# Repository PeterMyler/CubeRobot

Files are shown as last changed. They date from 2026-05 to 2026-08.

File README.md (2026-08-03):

 # Robot Rubik's Cube Solver
 
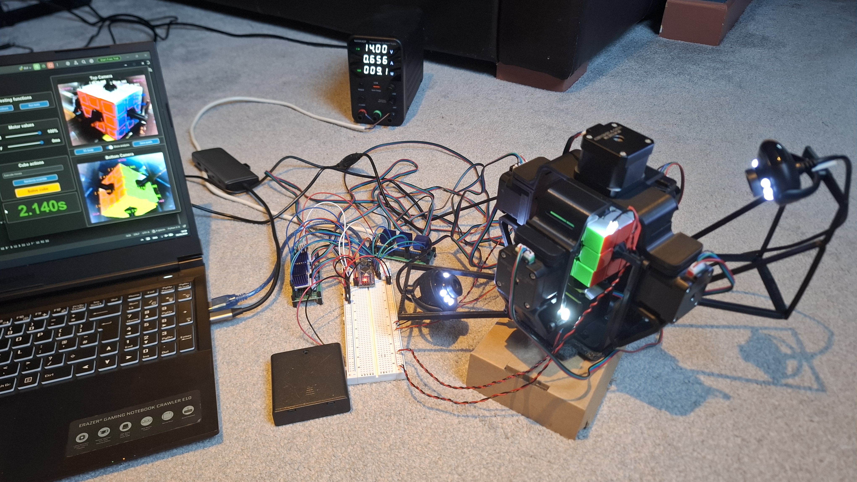
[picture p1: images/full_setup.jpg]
Completed robot assembly


An autonomous robot that scans, solves, and physically executes a solution to a scrambled 3×3×3 Rubik's Cube, with an average solve time of **2.13 seconds**, faster than the current human world record (2.76s).

Final Year Project for BEng (Hons) Electrical and Electronic Engineering (TU821), Technological University Dublin

**Author:** Peter Myler · **Supervisor:** Frank Duignan · May 2026

The project achieved a score of 86% and the student graduated with a 1st Class Honours (3.6 GPA).

**[Watch the demo video](https://youtu.be/nHWHOQfeOHc)**

---

## Overview

Place a scrambled cube in the robot, press one button, and it's solved, meaning no other input required. The system combines:

- A custom 3D-printed frame with **six NEMA 17 stepper motors**, one per cube face
- **Two USB webcams** for full cube-state capture via HSV colour detection
- **Kociemba's two-phase algorithm** to compute a near-optimal solution
- An **Arduino Nano** driving six TMC2208 stepper drivers to execute the moves
- A **Python GUI** for monitoring, calibration, and automated testing

| Metric | Result |
|---|---|
| Mean solve time | 2.13 s |
| Fastest solve | 1.5 s |
| Mean move count | ~19.8 moves (God's Number = 20) |
| Mean turn rate | 15.35 turns/sec |
| Success rate (200 test cycles) | 100% |
| Estimated real-world reliability | ~99% |

---

## Table of Contents

- [How It Works](#how-it-works)
- [Hardware](#hardware)
- [Repository Structure](#repository-structure)
- [Getting Started](#getting-started)
- [Usage](#usage)
- [Testing](#testing)
- [Results](#results)
- [Limitations](#limitations)
- [Future Work](#future-work)

---

## How It Works

```
    Host PC (Python)                 Arduino Nano                  Mechanical Frame
┌──────────────────────┐  USB    ┌─────────────────┐   Step/Dir  ┌──────────────────┐
│ GUI / control        │ serial  │ Firmware:       │   signals   │ 6× TMC2208       │
│ Camera capture (x2)  │ ◄─────► │  parses moves,  │ ──────────► │ drivers → 6×     │
│ HSV colour detection │         │  drives motors  │             │ NEMA 17 motors   │
│ Kociemba solver      │         │  via TMC2208s   │             │ (one per face)   │
└──────────────────────┘         └─────────────────┘             └──────────────────┘
```

1. **Scan** — Two webcams positioned at opposite corners of the frame capture all six faces. Facelet regions are sampled as HSV medians and classified by hue (with saturation/value tie-breaking for red/orange and yellow/green).
2. **Reconstruct** — The motor couplers physically obscure the six centre facelets and some corner facelets. Centres are inferred from the cube's fixed orientation (white up, green front); hidden corner facelets are recovered by matching the two visible facelets of a corner against the eight known corner-piece colour combinations.
3. **Solve** — The reconstructed cube state is passed to [Kociemba's two-phase algorithm](https://github.com/hkociemba/RubiksCube-TwophaseSolver) with a 0.1s search budget, returning a near-optimal move sequence (~20 moves).
4. **Execute** — The move sequence is sent over serial to the Arduino Nano, which generates step/direction pulses for the six TMC2208 drivers at a constant 320 µs step delay.
5. **Verify** — If the detected cubestring is invalid (a misclassified facelet), a single-error correction routine attempts to repair it before falling back to a fresh scan.

For more detail on the colour-space design, hidden-facelet recovery, and the two-phase algorithm, see the full [project report](./FYP_Report.pdf).

---

## Hardware

| Component | Details |
|---|---|
| Motors | 6× NEMA 17 (17HS4401), 1.8° step, 40 N·cm holding torque |
| Motor drivers | 6× TMC2208 silent stepper drivers (StealthChop) |
| Microcontroller | Arduino Nano |
| Cameras | 2× Trust Spotlight Pro USB webcams (640×480) |
| Motor power | 14V bench supply, 4.8A current limit |
| Logic/LED power | 6V (4× AA battery pack) |
| Frame | ~20 custom 3D-printed PLA parts (Fusion 360, printed on a Creality Ender-3 Neo) |
| Cube | Standard 3×3×3 speed cube with centre caps removed for motor couplers |

Full bill of materials is in the [report, Appendix C](./FYP_Report.pdf).

---

## Repository Structure

```
├── rubiks_solver_arduino/ # Arduino Nano firmware (step/direction motor control)
├── python/
│   ├── GUI.py              # Main application — UI, camera feeds, solve control
│   ├── Camera.py           # Camera capture + HSV colour classification
│   ├── Cube.py             # Cubestring construction, solver integration, serial comms
│   └── cube_data.json      # Camera IDs, motor speed/delay, facelet quadrilateral coords
├── cad/                   # Fusion 360 models
├── Test_data/             # Automated test run results (CSV)
├── images/                # Images of the components and frame
└── FYP_Report.pdf         # Full project report
```

---

## Getting Started

### Prerequisites
- Python 3.x
- Arduino IDE (to flash the Nano firmware)
- The hardware described above, assembled per the [CAD files](./cad) and wiring in the report (Section 5.2)

### Python dependencies
```bash
pip install opencv-python customtkinter pyserial RubiksCube-TwophaseSolver magiccube
```
(`cubescrambler` is used for generating WCA-compliant scrambles during testing — see its [repo](https://github.com/koma52/cubescrambler) for installation.)

> **Note:** `RubiksCube-TwophaseSolver` builds large lookup tables (~80 MB) on first use, which can take a while to generate.

### Flashing the firmware
Open `arduino/` in the Arduino IDE and upload to a connected Arduino Nano. No external libraries are required.

### Running the host software
```bash
cd python
python GUI.py
```
Set the correct camera device IDs and Arduino serial port in `cube_data.json` / at the top of `Cube.py` before running.

---

## Usage

1. Launch `GUI.py`.
2. Use **Calibrate colours** to run the HSV calibration routine (executes random moves and samples facelet colours under current lighting).
3. Insert the cube with **white up, green facing forward** (marked on the frame).
4. Click **Randomly scramble** to test, or scramble by hand.
5. Click **Solve cube** — the robot detects the state, computes a solution, and executes it automatically.
6. Adjust the **Speed** / **Delay** sliders to tune motor performance if needed (default: 320 µs step delay, 0 ms inter-move delay).

---

## Testing

An automated test procedure (`App.tester()` in `GUI.py`) runs a configurable number of consecutive scramble-and-solve cycles using WCA-compliant scrambles, logging success/failure, solve time, move/turn counts, and colour-detection attempts required. Raw results from the two formal 100-cycle test runs are in [`test_data/`](./test_data).

---

## Results

Two 100-cycle automated test runs were performed at the system's fastest reliable settings (320 µs step delay, 0 ms move delay):

| Metric | Run 1 | Run 2 |
|---|---|---|
| Success rate | 100% | 100% |
| Mean solve time | 2.117 s | 2.146 s |
| Fastest solve | 1.500 s | 1.781 s |
| Mean move count | 19.68 | 19.93 |
| Mean turns/sec | 15.35 | 15.35 |
| First-attempt detection success | 70% | 68% |

Motor execution accounts for ~90% of total solve time, with colour detection and solving making up the remaining ~10%. See [Chapter 6 of the report](./FYP_Report.pdf) for the full breakdown, including detection-attempt distributions and a reliability estimate (~99% under varied conditions).

---

## Limitations

- **Lighting sensitivity** — HSV-based classification is affected by ambient lighting changes despite supplementary LED illumination.
- **Open-loop motor control** — no feedback on whether a step actually produced the expected rotation; a lost step mid-solve wouldn't be detected.
- **Single-error correction only** — the correction routine can fix one misclassified facelet per attempt; scrambles with multiple simultaneous borderline facelets can exceed the 200-attempt retry limit.

---

## Future Work

- Acceleration ramping / BLDC motors with encoders for faster turns
- Custom PCB to replace the breadboard/protoboard assembly
- Per-facelet HSV calibration and automated quadrilateral placement
- Multi-error correction for cube-state detection
- Migration to a self-contained Raspberry Pi appliance with onboard display/controls
- Single, purpose-built 14V/6V power supply

Full details in [Section 7.3 of the report](./FYP_Report.pdf).

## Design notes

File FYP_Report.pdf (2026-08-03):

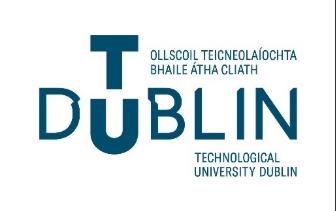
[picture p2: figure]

# Robot Rubik’s Cube Solver

By

Peter Myler

This report is submitted in partial fulfilment of the requirements of the Honours Degree in Electrical and Electronic Engineering (TU821) of

Technological University Dublin

May 25th, 2026

Supervisor: Frank Duignan

## Abstract

This report describes the design, construction, and evaluation of an autonomous robotic system capable of solving a scrambled 3×3×3 Rubik’s cube. The robot consists of a custom 3D-printed mechanical frame holding six stepper motors, each connected directly to one face of the cube via a custom 3D-printed motor coupler. Two USB webcams capture images of all visible facelets, which are processed using HSV-based colour detection to construct the cube’s current state. Kociemba’s two-phase algorithm computes a near-optimal solution sequence, which is transmitted from the host computer to an Arduino Nano microcontroller over a serial link. The microcontroller drives the six stepper motors through stepper drivers to execute the solution. A custom graphical user interface allows the user to monitor the camera feeds, adjust system parameters, calibrate the colour detection, and execute random scrambles and solves.

The completed system solves a scrambled cube successfully on approximately 99% of attempts, with the remaining failures attributable to occasional misclassification by the colour detection stage under varying lighting conditions. Successful full solves, which include the colour-detection, solution computation and physical execution stages, complete in an average time of 2.13 seconds, with a fastest recorded solve of just 1.5 seconds – significantly faster than the current official human world record of 2.76 seconds [23]. The project demonstrates the integration of mechanical design, electronics, embedded systems, computer vision, and software into a single autonomous system, and provides a practical platform for the demonstration of applied robotics.

## Declaration

I confirm that the content of this document is my own original work, except where otherwise acknowledged. This includes all text, figures, tables, schematics, and images, etc.

Furthermore, I declare that this document, and the work described herein, has not been submitted for a degree or other award at any other university or institution.

I confirm that I am familiar with the university’s policy on appropriate use of artificial intelligence https://tudublin.libguides.com/GenAI/guidelinesresources.

Generative AI was not used during this project.

Student Signature: Peter Myler

Date: 25/05/2026

## Table of Contents

## 1 Introduction

The Rubik’s Cube is one of the most recognisable mechanical puzzles in the world. Despite its simple appearance, the number of possible scrambled states exceeds 43 quintillion, higher than the total number of grains of sand on Earth. Solving it autonomously requires combining mechanical design, electronics, embedded systems, computer vision, and software into a single interconnected system.

The aim of this project was to design and build a fully autonomous Rubik’s Cube solving robot. The system allows a user to scramble a standard 3×3×3 Rubik’s Cube by hand, place it into the robot, and start the solving process through a graphical user interface. After that, no further input or manual help is needed. The robot identifies the current state of the cube, computes a solution, and executes the moves automatically.

The robot consists of a custom 3D-printed frame holding six stepper motors, each rotating one face of the cube. Custom motor couplers connect each motor directly to a face of the cube. Two USB webcams positioned at opposite corners of the robot capture images of all six faces, which are processed using HSV-based colour detection to determine the state of the cube. Kociemba’s two-phase algorithm then computes a near-optimal solution, which is sent over a serial link to an Arduino Nano microcontroller. The Arduino drives the six stepper motors through stepper drivers to physically execute the solution on the cube. The host-side software, written in Python, runs on a PC or laptop and provides a graphical user interface for monitoring, calibrating, testing, and controlling the robot.

The primary objectives of the project were:

| • To design and build a robust mechanical frame capable of holding six stepper motors and securing the Rubik’s Cube during operation. • To implement accurate and reliable stepper motor control using a microcontroller. • To develop a computer vision algorithm capable of detecting the colour of each facelet and determining the full cube state. • To integrate an efficient solving algorithm and translate its output into executable motor commands. • To develop a graphical user interface for user control and real-time system monitoring. • To combine all subsystems into a fully autonomous and reliable robotic system.

The remainder of this report is structured as follows:

| • Chapter 2 covers the ethical considerations relevant to the project.

- Chapter 3 provides background research on the key technical areas behind the system, including cube-solving algorithms, motor and driver selection, computer vision approaches, and a review of existing designs.
- Chapter 4 describes the overall system architecture and the key design decisions. Chapter 5 covers the implementation of each subsystem in detail.
- Chapter 6 documents the testing and results.
- Chapter 7 presents the conclusions and ideas for future work.

## 2 Ethics

This chapter covers the ethical considerations relevant to the design, construction, and use of the Rubik’s Cube solving robot. The project does not involve human subjects, clinical applications, or the processing of personal data, but a few ethical considerations are still relevant.

## 2.1 Health and Safety

The robot involves mechanical motion, electrical power, and the use of workshop tools during construction, all of which introduce potential safety risks.

During construction, soldering, wiring, and general assembly were carried out following standard laboratory safety practices, including working in a well-ventilated area and using appropriate personal protective equipment. The 3D printer used to manufacture the mechanical parts was operated following its standard operating procedure, with attention paid to ventilation and unattended operation.

During operation, the six stepper motors rotate the faces of the cube at significant speed and torque, which introduces a risk of finger entrapment if the mechanism is started while hands are inside the frame. To mitigate this, the system only starts a solve through the user interface, after the user has placed the cube and moved their hands clear. The electrical system runs at 14 V with a 4.8 A current limit. Idle current draw is around 0.7 A, rising to roughly 2–3 A during operation. All components run within their rated voltage and current limits, and appropriate insulation and strain relief are used throughout the wiring.

## 2.2 Professional and Technical Responsibility

The project was developed following accepted engineering practice, including proper documentation, structured testing, and iterative validation of each subsystem. As set out in Engineers Ireland’s Code of Ethics, engineers are expected to take responsibility for the quality and safety of their work and to act with integrity in all professional matters [24].

The most significant external dependency in the project is the RubiksCube-TwophaseSolver library by Herbert Kociemba [4]. This library is published under the GNU General Public Licence v3.0 (GPL-3.0), which permits free use, modification, and distribution as long as any derivative work is distributed under the same licence. The library has been used strictly in accordance with these terms. It has not been modified and is properly referenced throughout this documentation. No other external libraries with restrictive licensing terms were used.

All design decisions, implementation choices, and engineering judgements were the independent work of the student, with guidance from the project supervisor. The system was designed to behave predictably and safely.

## 2.3 Data Protection and Privacy

The project uses two cameras to capture images of the Rubik’s Cube during the colour detection stage. These cameras are pointed only at the cube within the robot’s frame and cannot capture images of people in normal operation. Captured images are processed in memory and are not saved to disk or stored beyond the duration of a single solve cycle. Since the system does not collect, store, or transmit any personal data, the General Data Protection Regulation (GDPR) does not apply to this project. This was a deliberate design choice, to keep the system simple and free of any data protection obligations.

## 2.4 Societal and Educational Impact

Although this project is primarily a technical and educational exercise, it shows the integration of mechanical design, electronics, embedded systems, computer vision, and software into a single autonomous robotic system, a combination of disciplines that is increasingly relevant in modern engineering.

The system could serve as a useful demonstration platform for illustrating concepts in robotics, control systems, and computer vision to undergraduate students. In this respect, the project contributes to the 4th United Nations Sustainable Development Goal [25]: to ensure inclusive and equitable access to quality education and promote lifelong learning opportunities for all by providing a tangible, accessible demonstration of applied engineering.

## 2.5 Use of Artificial Intelligence

No artificial intelligence tools were used at any stage of this project, including during software development, the design of the mechanical and electronic systems, or the preparation of this documentation. All technical work, implementation, design decisions, and written content are the independent work of the student.

## 3 Background and Research

The development of an autonomous Rubik’s Cube solving robot requires research across several technical areas, including cube-solving algorithms, mechanical design, motor selection, embedded systems, computer vision, and serial communication. Existing documentation, open-source libraries, project build logs, and video demonstrations of similar systems were reviewed to inform the design decisions made for this project [3]-[23]. This chapter summarises the key findings.

## 3.1 Rubik’s Cube Terminology and Notation

Before discussing the algorithms and engineering challenges involved in solving a Rubik’s Cube autonomously, it’s useful to establish the terminology used throughout this report.

The standard Rubik’s Cube has 26 individual physical pieces called cubelets, arranged in a 3×3×3 grid around an internal mechanism that allows each face to rotate independently (the cubelet in the exact centre of the grid is not counted). These cubelets fall into three categories: 8 corner cubelets (each with three visible coloured faces), 12 edge cubelets (each with two visible coloured faces), and 6 centre cubelets (each with a single coloured visible face). The individual coloured surfaces on each cubelet are called facelets rather than “stickers”. The arrangement of all facelets across the cube at any given moment is referred to as the current cube state.

Slice moves rotate one or more of the inner layers rather than the outer faces. However, any slice move is geometrically equivalent to rotating the two outer faces parallel to it in the opposite direction. As a result, slice moves don’t add any extra capability beyond the six standard face rotations. This is why a six-motor robot, with one motor per face, is mechanically sufficient to perform every possible cube manipulation. The colour of each centre therefore defines the colour of its face, as well as the orientation of the cube as a whole. This property has important implications for cube-solving algorithms and, as discussed later, for camera-based cube state detection.

Face rotations are described using Singmaster notation [21] (Appendix B), which assigns a single letter to each of the six outer faces: U (Up), D (Down), L (Left), R (Right), F (Front), and B (Back). A single letter (e.g. R) means a 90° clockwise rotation when looking straight onto the face. An apostrophe (e.g. R’) means a 90° anticlockwise rotation, and a numeric suffix of 2 (e.g. R2) means a half-turn or 180° rotation.

It is also important to note the distinction between “moves” and “turns”. Moves are defined as any face rotation regardless of the angle, so R, R’, and R2 all each count as 1 move. Turns are defined in terms of how many half-turns were made, so R and R’ each count as 1 turn and

R2 is counted as 2 turns. This means that even though God’s number is 20 moves, it is actually closer to 28 turns on average.

## 3.2 Kociemba’s Two-Phase Algorithm

A key part of any cube-solving system is the algorithm used to compute the solution. Several approaches exist, ranging from layer-by-layer methods to computationally efficient near-optimal solvers. The layer-by-layer method known as CFOP is used by the vast majority of the speed-solving community. While it’s a great method for a human, it can require over 60 moves to solve a properly scrambled cube. It has been proved that any scramble can be solved in 20 moves or less [22], which is known as God’s Number. Since CFOP usually requires well over that move count, it is impractical for a fast robotic system.

Kociemba’s two-phase algorithm is a well-documented method that solves this by breaking the solution process into two constrained search phases [3]. In the first phase, the algorithm manipulates the cube into an intermediate state called G1, in which all corners and edges are oriented correctly and all middle-layer edges are in the middle layer. From this state, the second phase solves the rest of the cube using a restricted set of moves: 180° half-turns for the F, B, L, and R faces, combined with any rotation of the U and D faces. By restricting the second phase like this, the search space is dramatically reduced, allowing efficient computation of a near-optimal solution.

The algorithm uses large precomputed lookup tables to guide the search, requiring around 80 MB of storage and taking some time to generate on first use [4]. After that initial cost, solutions of around 22 moves can be found almost instantly. An iterative deepening search is used to progressively find shorter solutions within a given time budget, although this feature went mostly unused in the project itself as the time limit given to the solver was quite short.

An open-source Python implementation of this algorithm is available as an installable package
[4] and maintained by Herbert Kociemba himself! Using a proven and well-tested library allowed the project to focus on system integration and reliability rather than algorithm development from scratch.

## 3.3 Existing Designs

Several existing Rubik’s Cube solving robots were examined through project build logs and video demonstrations [5]-[11]. These sources provided practical insight into mechanical and electrical design choices, common implementation challenges, and the relative merits of different approaches.

Kostoski [5] documents the iterative development of a six-motor stepper-based solver. The build log gives useful insight into the practical challenges of motor-to-cube coupling and the importance of frame rigidity, and also highlights the limitations of lower-torque motors – an important consideration during motor selection for this project.

Musa [6], [7] presents a similar six-motor design using NEMA 17 steppers driven by TMC2208 silent stepper drivers. All his parts were 3D-printed in PLA at 20% infill. The project shows a mechanical solution for motor-to-cube coupling using custom-printed adapter pieces. A later video by the same author [11] shows an upgraded design using brushless DC motors with magnetic encoders, achieving significantly faster solve times.

Flatland [8] demonstrates one of the fastest stepper-based robotic solvers publicly documented, showing the upper bounds of what’s achievable with a well-tuned design.

## 3.4 Alternative Designs

Alternative mechanical architectures were also considered. The CUBOTino project [9] and a dual-axis design by HiDe Tech [10] both use fewer than six motors, instead rotating the entire cube to bring different faces into a position where they can be manipulated. While these mechanisms are interesting demonstrations of what can be done with minimal hardware, they add significant complexity to both the mechanical design and the software control logic.

These designs are also much slower as repositioning the entire cube between moves adds significant dead time that isn’t spent directly executing moves on the cube. They are also more prone to alignment errors.

It’s also worth mentioning that it is theoretically possible to solve a Rubik’s Cube by being able to turn only five of the faces. However, this approach requires up to 13 extra moves of the other faces just to rotate the stationary face once, drastically increasing solve time.

Given the project’s goals of reliability, speed, and mechanical simplicity, these reduced-motor approaches were rejected. The six-motor architecture was selected as it maps each motor directly to one face, simplifies the control logic, and allows any move sequence produced by the solver to be executed directly.

## 3.5 Motor Selection

Motor selection was an important design decision affecting cost, control complexity, solve speed, and reliability. Two main options were considered: stepper motors and brushless DC (BLDC) motors with encoders.

BLDC motors can reach very high rotational speeds and are used in the highest-performance cube-solving machines [11]. However, they require more complex control electronics, closed-loop feedback via encoders, and careful tuning to be reliable. The extra cost and complexity make BLDC motors less suitable for a first-time integrated robotics project where reliability and simplicity are prioritised.

Stepper motors were selected due to their inherent positional accuracy, straightforward interface with microcontrollers via step and direction signals through drivers, and predictable behaviour. NEMA 17 motors in particular were identified through the reviewed projects [5]-
[6] as the most reliable choice for this application. The specific motor selected was the 17HS4401 [12], offering 40 N·cm of holding torque and a 1.8° step angle. Slower and lower torque alternatives such as the 28BYJ-48 stepper motor were found to produce inconsistent rotations and were unsuitable [5].

## 3.6 Stepper Motor Drivers

Stepper motors cannot be driven directly from a microcontroller. They require a dedicated driver circuit to convert step-and-direction logic signals into the higher-current coil patterns needed to rotate the motor. The two most common driver ICs in hobbyist robotics are the A4988 and the TMC2208.

The A4988 is a long-established and inexpensive driver capable of supplying up to roughly 2 amps per coil [14]. It’s well suited to lower-cost projects but uses a simple chopper drive that produces very loud coil whine. It can also lose synchronisation at high step rates, causing missed steps and inaccurate rotations.

The TMC2208 is a more modern silent stepper driver developed by Trinamic Motion Control, widely used in 3D printers for its quiet operation [13]. It uses StealthChop, which drives the motor coils smoothly with voltage-mode control rather than the abrupt current chopping used by the A4988. This produces much less noise and noticeably smoother motion.

## 3.7 Colour Detection

Reliable identification of the cube’s current state is needed for computing a correct solution. The reviewed projects use two broad approaches: manual input, where the user enters the colour of each tile through an interface, or automated camera-based detection [5]-[11].

Manual input methods avoid the technical challenges of computer vision entirely but rely on the user to correctly identify and enter each of the 54 facelet colours. This is error-prone and adds significant time to the overall solve. Camera-based detection lets the system operate much faster and is, most importantly, fully autonomous.

The reviewed designs that implement camera-based detection use traditional image processing techniques like colour-space analysis, rather than machine learning. This is appropriate for the controlled environment in which the robot operates, where lighting and camera positions are mostly consistent. HSV (hue, saturation, value) colour space methods are well suited to this kind of environment, are computationally lightweight, and don’t require training data. For these reasons, a camera-based HSV detection approach was selected for this project.

## 3.8 Serial Communication

In a system where the solving algorithm runs on a host computer and motor control runs on a dedicated microcontroller, a reliable communication interface between the two is required. There are two general options available: serial link over a physical cable and Bluetooth. A serial link provides better reliability, simplicity, and no pairing overhead. Therefore, a standard direct serial connection over a USB cable was used in this project.

## 3.9 Cube State Detection with Partial Visibility

A practical limitation of any six-motor cube-solving design is that the motor couplers occupy the position of the centre facelet on each face. Six facelets (one per face) are physically obscured and cannot be seen by any external camera. Depending on the geometry of the couplers and camera positions, the couplers may also block some corner facelets adjacent to each face. This raises a question that needs to be addressed during design: if some facelets can’t be seen directly, how can the full cube state be determined?

Fortunately, this is easily solvable in both cases! Since slice moves are not used – the centre piece of each face is fixed relative to the rest of the cube, meaning they cannot be moved by any sequence of face rotations. The colour of each centre facelet is therefore determined entirely by the cube’s known orientation in the robot (green as Front and white as Up).

As for the hidden corner facelets: a Rubik’s Cube has eight corner pieces, each with a unique combination and relative orientation of three facelet colours. If two of the three facelets on a corner are visible, the third can be determined by identifying which of the eight possible corner pieces the visible pair belongs to. The orientation of the corner, which is set by the relative spatial arrangement of the two visible facelets, tells you which colour the hidden facelet is.

Together these techniques allow a six-motor design to use just two cameras to detect the entire cube state.

## 4 System Design and Architecture

This chapter describes the overall architecture of the system and the key design decisions made for each subsystem before implementation. The goal is to give a complete picture of what was designed and why, before the implementation detail is covered in Chapter 5.

## 4.1 System Architecture Overview

The system has three main hardware elements: a host computer, an Arduino Nano microcontroller, and the mechanical frame itself, which houses the motors and USB webcams. A high-level block diagram is shown below:

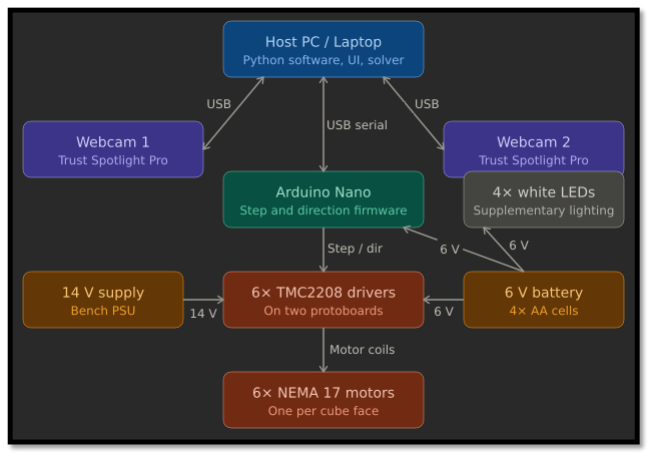
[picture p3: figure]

Figure 4-1. System block diagram

The host computer handles all high-level functionality: it runs the user interface, captures images from the two webcams, performs colour detection, runs the Kociemba two-phase solver, and sends the resulting move sequence to the Arduino Nano. The microcontroller receives the move sequence, interprets each move, and generates step and direction signals for the six stepper drivers, which in turn drive the six stepper motors. Once the full sequence has been executed, the microcontroller sends an acknowledgement back to the host.

This division of responsibilities was a deliberate design choice. The Kociemba algorithm has substantial computational and memory requirements making it unsuitable for a low-power microcontroller. Generating accurate step-and-direction signals at hundreds of microsecond intervals requires precise real-time timing, which is far easier on a dedicated microcontroller than on a general-purpose operating system. Splitting the work this way lets each device do what it’s best suited to.

## 4.2 Mechanical Design

The mechanical design uses the six-motor architecture established in Chapter 3, with one stepper motor mounted on each face of a cubic frame, oriented to drive the corresponding face of the cube. The frame is fully 3D-printed in PLA and held together with M3 screws and nuts throughout, so any part can be replaced or modified easily.

Motor-to-cube coupling. Two approaches were considered. The first, used in some existing designs, is to insert 3D-printed adapters into the cube’s centre caps [6]. This was rejected because it significantly modifies the cube itself and makes it uncomfortable to scramble by hand. The other approach is to remove the centre facelet of each face (which is a simple cover) and design a coupler that fits into the recessed cavity beneath. This keeps the cube’s physical shape and feel while providing a strong mechanical connection to the motor shaft. The coupler is octagonal in profile to match the cavity, with a cylinder containing a D-shaped hole that fits the flat on the stepper motor shaft.

Frame rigidity and cube insertion. A fully rigid frame would prevent the cube from being inserted between the motors, since the cube and the couplers need to be in contact. Some mechanical compliance is therefore needed. The four side mounts (Left, Right, Front, Back) can flex slightly outwards to allow the cube to be placed inside, but must be held rigidly in place during operation to keep the motor shafts aligned. To achieve this, the top mount interlocks with the four side mounts, locking them in place once fitted. Additional 3D-printed brackets clamp the top down to the sides to prevent any movement during operation.

Print orientation for structural integrity. An early version of the base with all four side mounts as a single part was printed, which left the individual layer lines with a very small surface area. Two sides snapped cleanly along the layer lines under some slight bending.

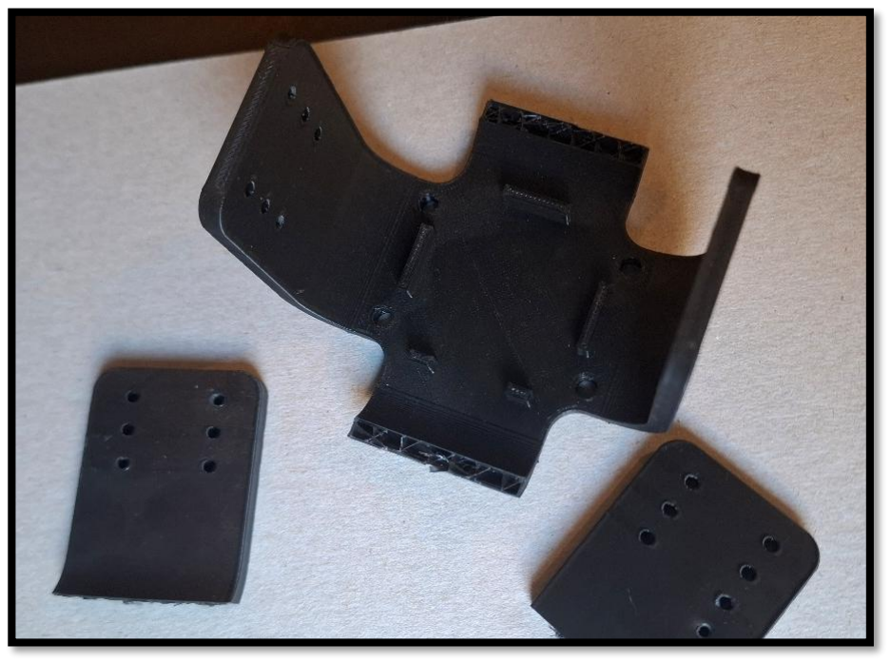
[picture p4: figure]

Figure 4-2. Failed 3D-printed base

The revised design splits the base into two pieces, allowing each to be printed on its side so the layer lines have much higher surface area and run perpendicular to the stress direction. This significantly increased the amount this part could flex and resolved the snapping problem. Heat-set inserts were used to join the parts together and bolt the bottom motor.

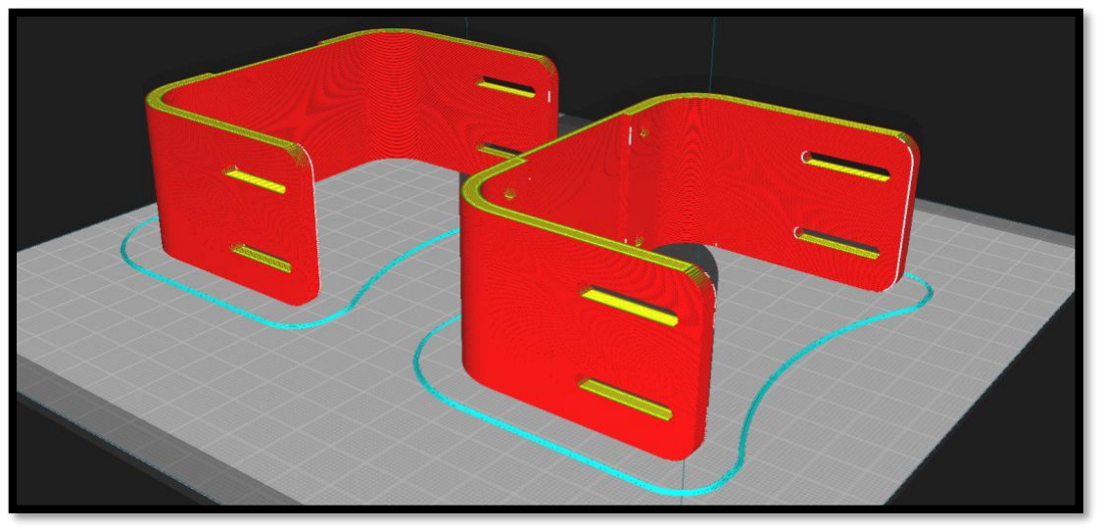
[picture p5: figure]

Figure 4-3. Revised base pieces

## 4.3 Electronics Design

The electronics subsystem covers the microcontroller, the six stepper motor drivers, the power supply, and the supplementary lighting needed for reliable colour detection.

Microcontroller. An Arduino Nano [15] was selected as the motor controller. It provides enough digital I/O for the twelve step-and-direction signals needed by the six drivers, has well-supported development tools, and can be programmed and powered over a single USB connection from the host. More capable microcontrollers were considered, but the project didn’t need anything beyond the Nano’s capabilities.

Stepper drivers. Initial testing used A4988 drivers, which are widely available and inexpensive. In practice these produced loud audible coil whine, ran the motors more slowly than expected, and behaved unreliably at higher step rates, occasionally missing steps. The drivers were replaced with TMC2208 silent stepper drivers, which resolved all three issues: operation became almost silent, achievable step rates were higher, and rotations were consistently accurate. The TMC2208 is pin-compatible with the A4988, so the swap was straightforward. The lowest microstepping setting on the TMC2208 was selected, since the system only ever performs 90° or 180° rotations.

Power supply. The motors are powered by a variable bench power supply set to 14 V with the current limit at 4.8 A. Although idle current draw is around 0.7 A and normal operation is around 2-3 A, the initial inrush current of all six motors at startup is much higher, and a lower limit prevented the motors from initialising properly. The Arduino and supplementary lighting are powered separately from a 6 V battery pack (four AA batteries).

Supplementary lighting. Although the chosen webcams have integrated white LEDs around the lens, in practice these don’t provide enough or sufficiently uniform illumination to reliably detect colours across all visible facelets. Four extra white LEDs were added: two for the top camera’s field of view, and two for the bottom. These ensure that all visible faces are more evenly lit.

## 4.4 Vision System Design

The vision subsystem captures images of the cube and determines its current state. Two USB Trust Spotlight Pro webcams are positioned at opposite corners of the robot so that all six faces are visible across the two cameras combined. These were selected for their low cost, adjustable mounting, and integrated lighting.

Colour space selection. An initial implementation used the mean RGB value of each facelet’s image region. This was unreliable because RGB couples colour information with brightness – the same red facelet can produce significantly different RGB values under different lighting, leading to misclassifications even with the supplementary lighting. The system was moved to HSV (hue, saturation, value), which separates hue from brightness and saturation, allowing classification to be based primarily on hue and made far more robust to lighting variation.

Statistical measure. Within each facelet’s region, a statistical measure of the pixel colour is needed. The mean was tried first but was found to be sensitive to outlier pixels caused by edge effects, glare, dust, or imperfections in the printed facelet boundaries. The median was found to be much more robust and was therefore adopted.

Region definition. Each facelet’s region is defined by a quadrilateral, a four-vertex polygon, with each vertex being able to be positioned independently. Quadrilaterals were chosen rather than rectangles because the cameras view the cube from oblique angles, and the apparent shape of each facelet in the image is a perspective-projected quadrilateral rather than a square. Defining the region this way allows accurate sampling without needing any image rectification.

Hidden facelet recovery. As discussed in Section 3.9, some facelets are blocked by the motor couplers. The six centre facelets are filled in deterministically based on the cube’s known orientation. The obscured corner facelets are recovered by identifying which of the eight unique corner cubelets the visible pair belongs to, and using the spatial arrangement of those two facelets to determine the orientation of the corner and therefore the colour of the hidden third facelet.

## 4.5 Software Architecture

The host computer software has four main parts: the user interface, the camera capture and colour detection pipeline, the solver interface, and the serial communication module.

The user interface is implemented using CustomTkinter [17] and runs on the main thread. It displays the live camera feeds, presents controls for testing and calibration, and starts solves. The camera capture pipeline, implemented using the OpenCV library [16], runs continuously in the background, providing the most recent frame from each camera on demand. When a solve is started, the most recent frames are passed to the colour detection module, which extracts the cube state and passes it to the solver. The solver returns a move sequence, which is translated from Kociemba notation to standard cube notation and then sent to the Arduino over the serial link using pyserial [18].

One design consideration is that the serial read used to wait for the Arduino’s acknowledgement is a blocking operation. If this were done on the main thread, it would freeze the entire UI, including the camera feeds, for the duration of the solve. To prevent this, the serial communication is handled asynchronously on a separate thread, letting the main thread keep updating the UI and camera feeds while a solve is in progress.

## 4.6 Microcontroller Firmware Design

The Arduino Nano firmware receives a move sequence as a single transmission over the serial link, parses it into individual moves, and executes each move by generating step and direction signals for the relevant stepper driver. Once the full sequence has been executed, the firmware sends an acknowledgement back to the host with the executed sequence and the total execution time.

Two parameters control execution speed: the inter-step delay, which determines how quickly the motor runs, and the inter-move delay, which adds a settling time between consecutive moves. Both are exposed to the user through the host UI so they can be adjusted during testing. The system was found to operate reliably with an inter-step delay of 320 µs and zero inter-move delay; shorter step delays caused the motors to lose synchronisation.

## 5 Implementation

This chapter describes the implementation of each subsystem of the robot, building on the design decisions established in Chapter 4. It’s organised by subsystem, starting with the mechanical build, followed by the electronics, the Arduino firmware, the vision pipeline, and finally the host-side software and user interface. A full bill of materials for the system is provided in Appendix C.

## 5.1 Mechanical Build

The mechanical assembly is made up of around 20 individual 3D-printed parts, all printed in black PLA at 0.2 mm layer height on a Creality Ender-3 Neo. Most parts use 20% infill with two perimeter walls, with higher infill and more walls used selectively for parts subject to greater mechanical load or that need to flex during cube insertion. Most structural parts are 5 mm thick. The completed assembly is around 190 × 190 × 190 mm in size, not counting the camera mounts which stick out about another 100mm on opposite sides of the frame.

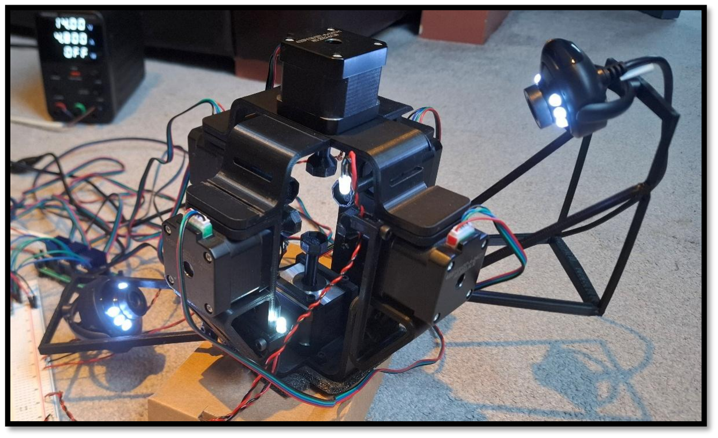
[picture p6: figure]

Figure 5-1. Completed assembly

The frame is held together using M3 screws and nuts, allowing any part to be replaced or modified with ease. This was valuable during development, when several parts had to be redesigned and reprinted to fix structural or spacing issues.

Motor couplers. Each motor is connected to its cube face via a custom coupler that fits into the cavity left after removing the cube’s centre facelet. The coupler is 33 mm long and has two main features: an octagonal head profiled to match the recessed cavity in the centre face of the cube, and an internal cylinder with a D-shaped hole that fits perfectly onto the stepper motor shaft. The design went through several iterations before achieving a good fit. Early versions either snapped, didn’t fit into the cube centre, or sat too loosely on the shaft. The final design provides a sturdy connection between motor and cube face.

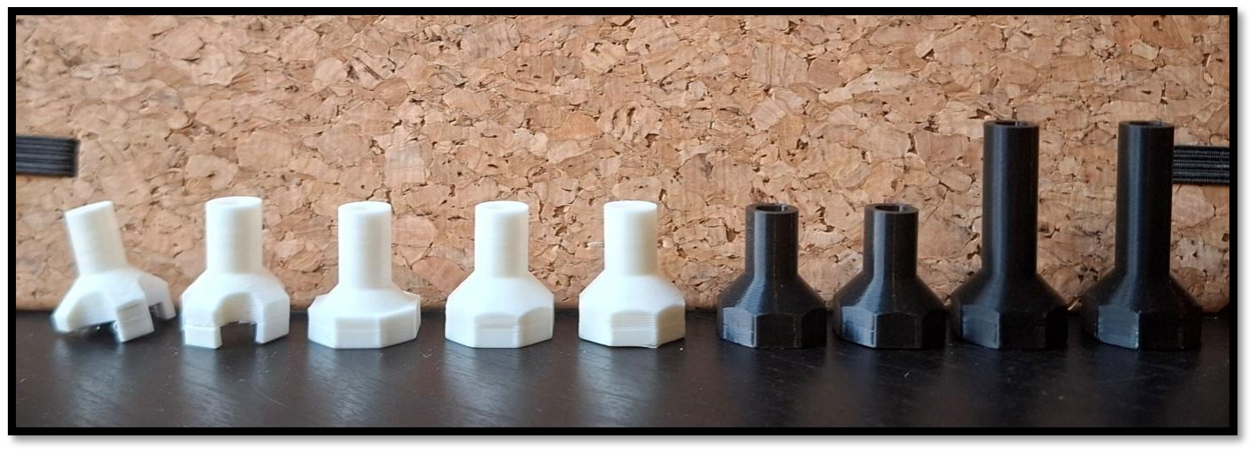
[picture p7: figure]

Figure 5-2. Motor coupler design iterations

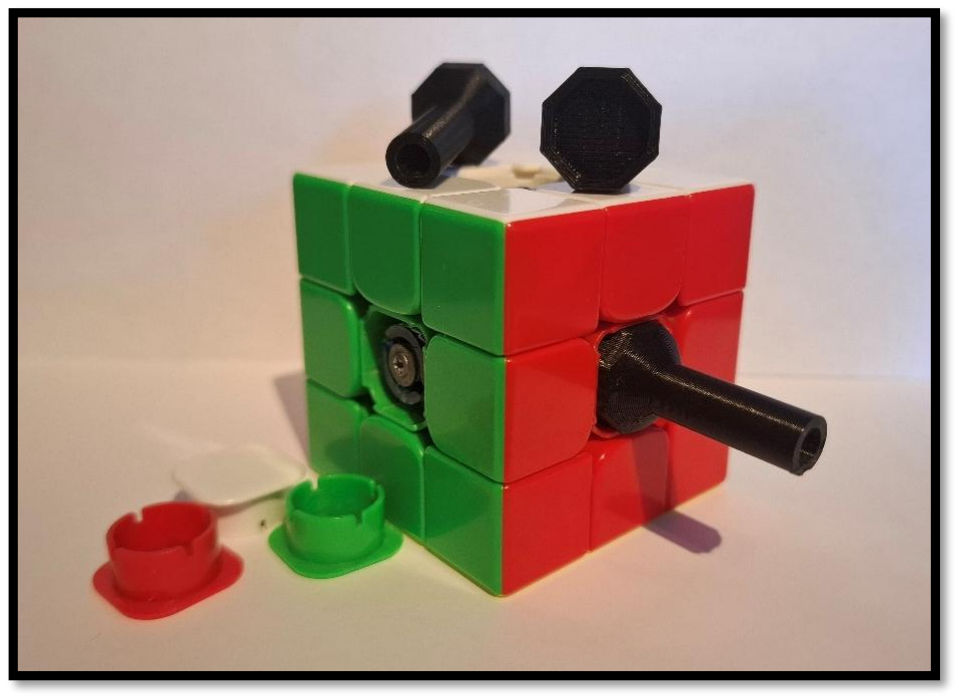
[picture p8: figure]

Figure 5-3. Motor couplers and cube

Mechanical frame. The frame was designed in Fusion 360. It consists of about 20 individual parts that join together with M3 nuts and bolts. The base consists of two separate U-shaped parts. The bottom stepper motor sits in the centre and is clamped down by two parts. Side mounts attach to each of the four sides of the base, which house the side stepper motors. The top part also consists of two parts joined together which sit on-top of the side mounts and are secured using some bracket parts to allow for easy disassembly. The top motor is bolted to the top parts.

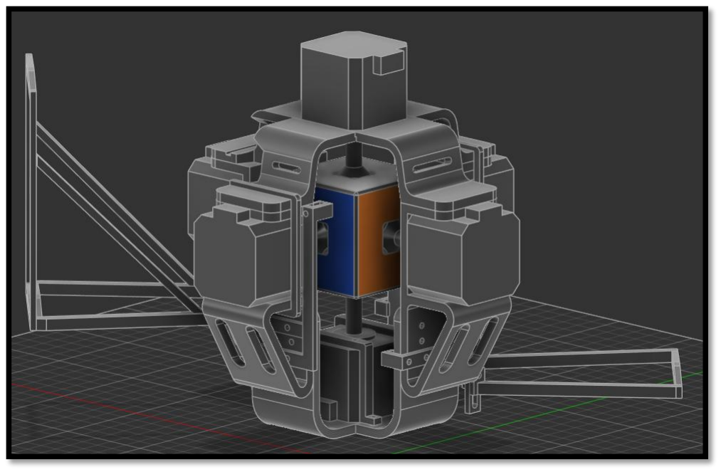
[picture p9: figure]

Figure 5-4. Fusion 360 model

Cube insertion. To insert the cube into the robot the top mount can simply be lifted up after removing the clamps that hold it down. The four side mounts can then be flexed slightly outwards to make room for the cube. The cube must be oriented with the white face up and the green face forwards. Physical markers on the frame show the correct orientation. Once the cube is seated against the bottom and all four side couplers, the top mount is put back and clamped down.

## 5.2 Electronics

The electronics are organised across three connected boards: a single breadboard with the Arduino Nano and the supplementary LEDs, and two protoboards each carrying three TMC2208 stepper drivers. Motor power comes from a NANKADF WPS3010H variable bench power supply set to 14 V with the current limit at 4.8 A. The Arduino and the supplementary LEDs are powered separately from a 6 V battery pack (four AA batteries).

Power distribution. The 14 V from the bench supply goes directly into the motor supply (VM) pin of each of the six TMC2208 drivers, providing the higher-current motor coil supply. The 6 V battery pack provides power to the Arduino (through its Vin pin), the TMC2208 logic supplies, and the four supplementary LEDs. Although the system draws around 0.7 A at idle and 2–3 A during normal operation, the simultaneous inrush current of all six motors at startup is significantly higher; the 4.8 A limit accommodates this transient without folding back the supply.

Driver protoboards. Each protoboard holds three TMC2208 drivers, with each driver sitting in soldered pin headers rather than being soldered directly. This lets a driver be swapped out easily if it fails (a useful feature given that a few TMC2208s were destroyed during development). The microstepping select pins are tied to ground on each driver, putting the TMC2208 in its lowest microstepping setting. The control pins are wired to another set of pin headers so that they can be connected with jumper wires to the Arduino. The motor coil pins are connected to a set of male pin headers which allow the wire which came with each stepper motor to be connected.

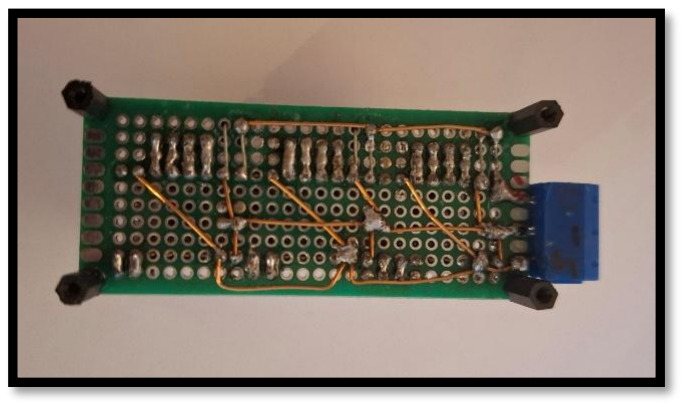
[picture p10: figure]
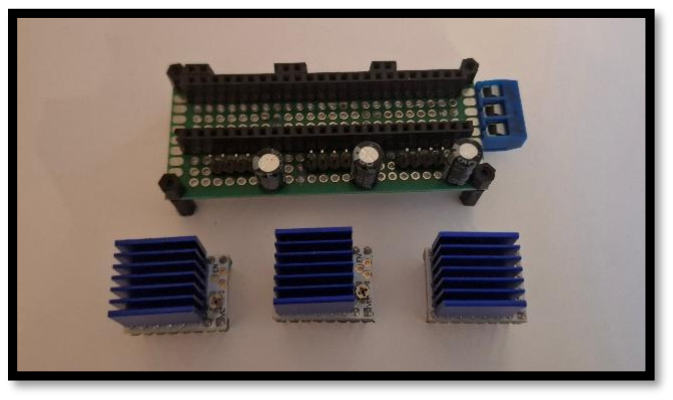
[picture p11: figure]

Figure 5-5. Driver protoboard without drivers Figure 5-6. Driver protoboard underside

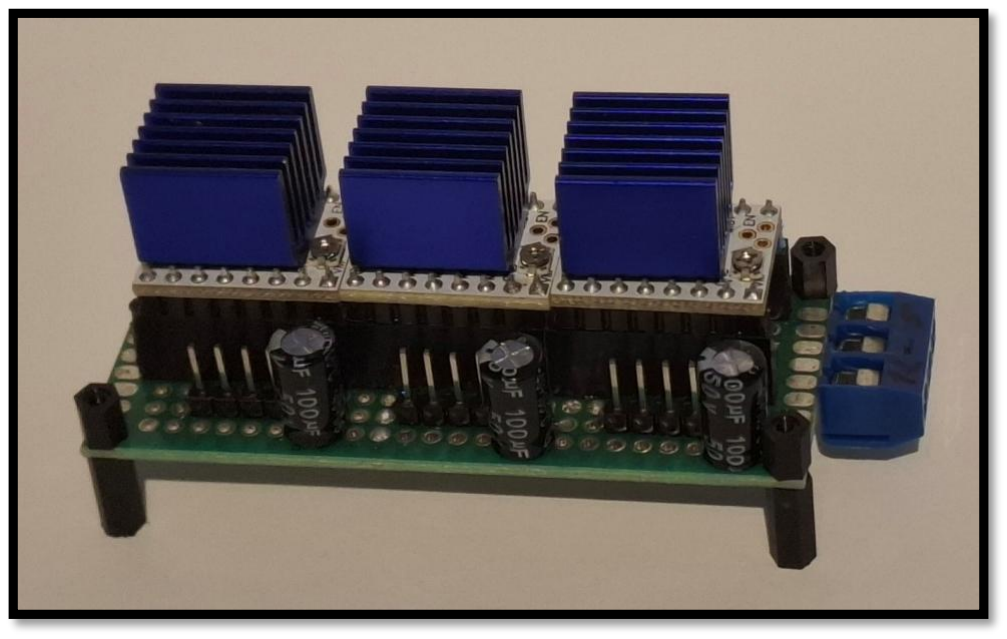
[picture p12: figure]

Figure 5-7. Driver protoboard

Wiring to the Arduino. Each driver needs two control signals from the Arduino: a step pulse and a direction signal. Twelve digital outputs are therefore needed in total. Pins 2 to 13 are used, with each driver receiving a step pin and a direction pin on consecutive numbers (driver 0 uses pins 2 and 3, driver 1 uses pins 4 and 5, and so on). Female pin connectors on each protoboard accept loose wires that run back to the breadboard, keeping the assembly modular. The mapping between motor index and cube face is handled in firmware via a lookup table.

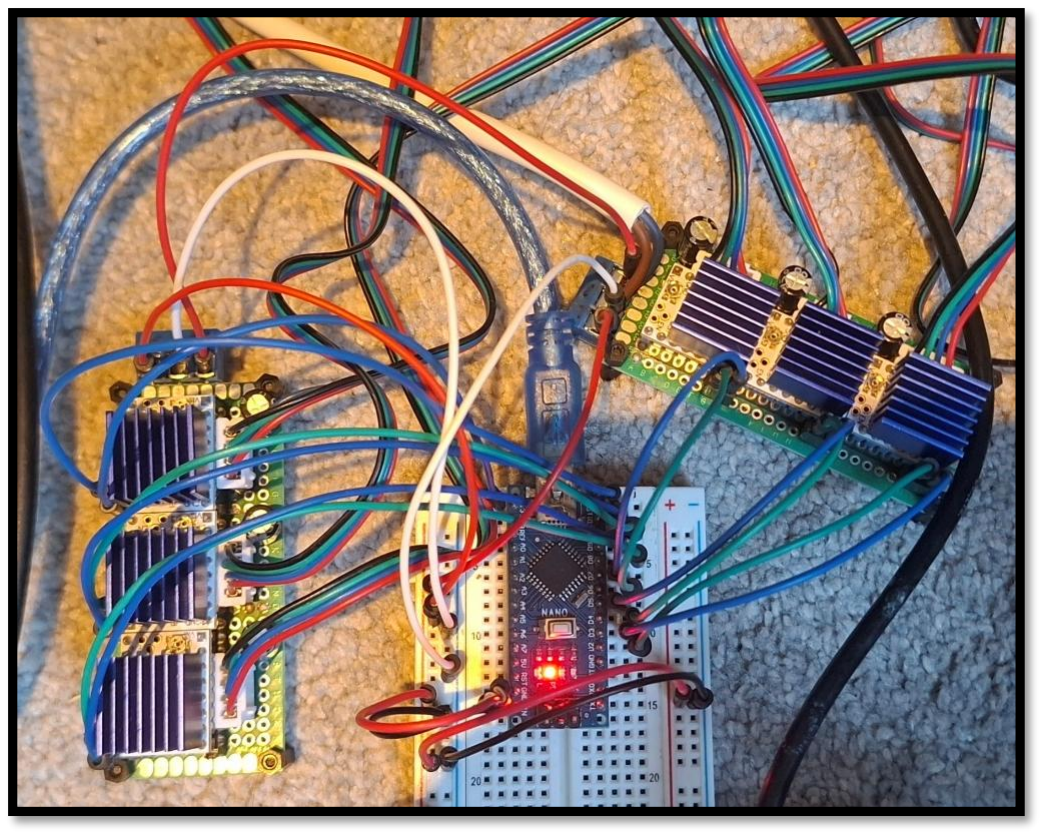
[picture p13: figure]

Figure 5-8. Drivers and Arduino

Supplementary lighting. Four extra white LEDs were added to provide enough illumination for colour detection – two for the top camera’s field of view and two for the bottom. The chosen webcams have integrated LEDs around the lens, but these alone don’t provide enough or sufficiently uniform light to reliably distinguish the six colours, especially at the oblique camera angles needed to see multiple faces. The supplementary LEDs are wired directly to the 6V battery rail on the breadboard.

## 5.3 Arduino Firmware

The Arduino Nano firmware is a single sketch of around 170 lines that handles all real-time motor control (Appendix A). The firmware is deliberately minimal, with no external libraries beyond the standard Arduino package.

Pin mapping and motor naming. Six pairs of step and direction pins are declared at the top of the sketch, alongside an array mapping motor index 0 to 5 to the corresponding face character (D, F, B, R, L, U). All face-name lookups go through a small search function which returns the motor index for a given face character, or -1 if the character isn’t recognised.

Step generation. Each 90° face rotation takes 100 step pulses (a 2× microstepping configuration on the 1.8°-per-step). A 180° rotation doubles this to 200 steps. Each step pulse is generated by setting the step pin HIGH for stepDelay microseconds, then LOW for another stepDelay microseconds, so each full step takes 2 × stepDelay. With the default stepDelay of 320 µs, the step rate is approximately 1560 steps per second. A constant step rate is used throughout each move. No acceleration ramping is implemented.

Move parsing. The main loop blocks on Serial.available() and reads incoming commands one line at a time. If the first character of the command matches a known face name, the command is treated as a move sequence; otherwise, it’s parsed as a parameter update. For move sequences, the firmware iterates through the command string, accumulating characters into a per-move buffer and dispatching each move on encountering a space. Each move is one or two characters: a face name optionally followed by an apostrophe (anticlockwise) or the digit 2 (180° rotation). The default direction is clockwise.

Parameter updates. Sending two integers separated by a space (for example, “320 100”) updates the delay in-between steps (speed) and the delay between moves (delay) parameters in real time. This lets the host easily adjust the speed and delay values of the motors without having to restart or reprogram the Arduino.

Acknowledgement. Once an entire move sequence is done, the firmware computes the total execution time using millis() and sends a single acknowledgement line back to the host containing the elapsed time, the number of moves, and the equivalent turn count.

## 5.4 Vision Pipeline – Camera.py

The vision subsystem runs entirely in Python on the host, using OpenCV [16] for camera capture and image processing. It’s implemented in Camera.py (Appendix A), with each of the two cameras represented by an instance of the Camera.Camera class (Appendix H-1).

Camera configuration. Cameras are connected to by using their respective Device Id stored in the json file (Appendix G). Each Camera instance is configured with a fixed resolution of 640×480, a hardware exposure setting, and a buffer size of zero to ensure that frames returned are always the most recent (Appendix H-1).

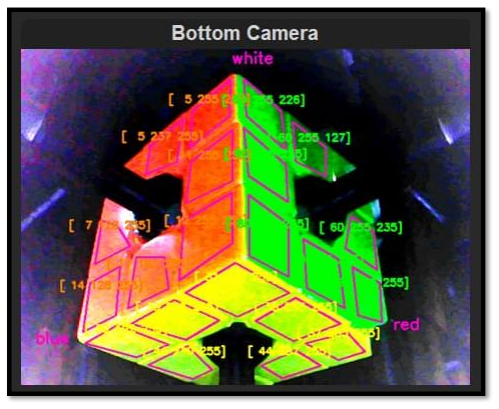
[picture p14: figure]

Figure 5-9. Bottom camera colour analysis

Frame preprocessing. Each frame is converted from BGR to RGB, flipped upside-down if necessary, and passed through cv2.normalize to expand its contrast (Appendix H-2) as the chosen webcams produce relatively dim images even with the supplementary lighting.

Quadrilateral sampling. Each visible facelet is associated with a quadrilateral defined by four vertex pixel coordinates stored in cube_data.json (Appendix G). The original implementation used simple small rectangular boxes positioned on each facelet, but this left a lot of their surface area unused. Switching to four-vertex quadrilaterals lets almost the entire visible surface of each facelet be sampled, significantly reducing the impact of grain and reflections on the classification result.

Hue-based classification. The classification function takes a single HSV tuple and returns one of the six colours (red, orange, yellow, green, blue, or white). The base classification uses a prewritten array of seven hue boundaries that partition the hue space into ranges for each colour (Appendix H-3). Unfortunately, hue alone isn’t always enough to classify colours under the lighting conditions. White detection is done first, before any hue-based classification, because white facelets have low saturation and aren’t reliably distinguished by hue alone. Red and orange are then disambiguated within the low-hue range using the value channel. A similar split is applied between yellow and green. These special cases were arrived at with some trial-and-error during testing. The implementation can be viewed in Appendix H-4.

Hidden facelet recovery. As discussed in Section 3.9, the motor couplers physically obscure some corner facelets on each camera. These are calculated by matching against a prewritten array (Appendix H-5) containing the colours of each of the eight corner cubelets, listed in top, right, front order. By knowing two colours of a corner piece and their relative order the third can be determined by iterating through the array and finding a match.

## 5.5 Cube State and Solver Integration – Cube.py

The construction of the full 54-character cubestring and the interaction with the Kociemba solver are handled in Cube.py (Appendix A).

The cubestring is built by mapping the visible facelet colours, the recovered hidden corner facelets, and the deterministic centre facelets into the index positions expected by the Kociemba library, using prewritten index arrays (Appendix D, Appendix E, Appendix I-2).

The cubestring is passed to the solver [4] (Appendix I-4) and is given a 0.1 second time limit to find the lowest-move solve it can. The solver can return an “Error” string, meaning the cubestring is invalid. This signals an incorrect reading in the colour detection stage. A correction algorithm (Appendix I-5) is ran which can correct for a single incorrect colour reading. If this correction fails the entire solve attempt is deemed as a failure.

## 5.6 Host Software and User Interface – GUI.py

The host software is split across three Python modules plus a JSON configuration file (Appendix A). GUI.py (Appendix J) is the main script, containing the App class which implements the user interface using CustomTkinter [17], as well as handling most of the general functionality. The file cube_data.json (Appendix G) holds the camera device IDs, motor speed and inter-move delay values, and the full set of quadrilateral coordinates for both cameras. Using an external configuration file separates these parameters from the source code, allowing them to be changed and saved without modifying the codebase.

UI structure. The user interface is built around a single App class that subclasses customtkinter.CTk. The window is split into two main regions:

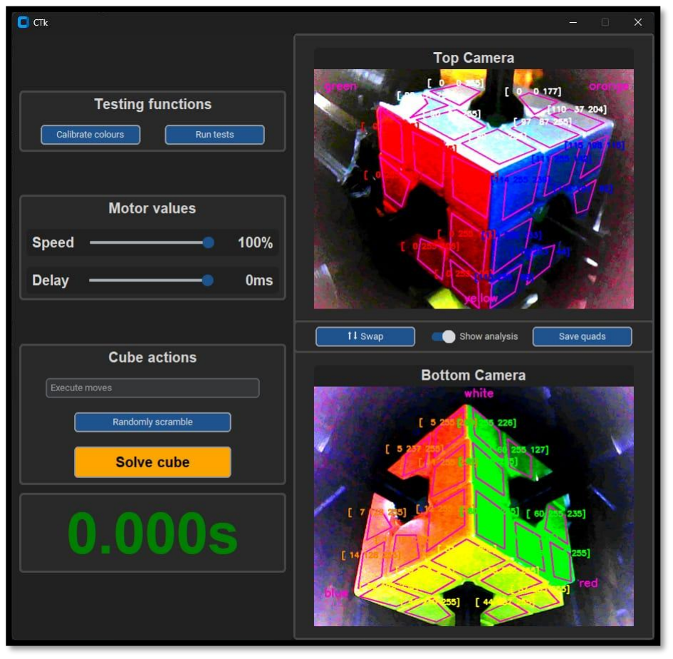
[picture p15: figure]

Figure 5-10. Python GUI

The right-hand region shows the live feeds from the top and bottom cameras, with controls for swapping the two cameras, toggling a colour analysis overlay (which displays the detected facelet colours and quadrilateral boundaries directly onto the camera feeds), and saving any adjustments made to the vertex positions.

The left-hand region contains the cube control functions, organised into three groups. The Testing Functions group provides access to the colour calibration routine and the automated test procedure. The Motor Values group has two sliders that control the inter-step delay and inter-move delay parameters. The Cube Actions group has an entry field for issuing arbitrary move sequences manually, a button for performing a random scramble (using WCA-compliant scrambles generated by cubescrambler [20]), and a button for starting a solve. A large solve timer is displayed beneath these controls.

Camera frame loop. Each camera has its own frame update loop, scheduled using the CustomTkinter self.after() method to grab a fresh frame at a configurable interval. When the colour analysis overlay is enabled, the frame is annotated with the quadrilateral outlines and the detected HSV values for each facelet before being displayed. When disabled the raw frame is unmodified apart from some scaling. The two cameras run on independent update loops so each updates as quickly as its own frame rate allows.

Direct command entry. The Cube Actions group's text entry field accepts arbitrary move sequences and forwards them directly to the Arduino. Sequences entered here aren't validated against the current cube state and don't invoke the solver. This was useful during development, both for testing individual motors and for issuing the special two-integer commands that update the firmware's step delay and inter-move delay.

Colour calibration. The calibration routine executes a series of random moves, samples the colour of each facelet within each quadrilateral after every move, and aggregates the samples to produce a set of HSV hue ranges that can reliably distinguish the six colours under the current lighting. A virtual representation of the cube is maintained throughout this process using magiccube [19], which tracks which physical facelet ends up in which position after each move so that samples can be correctly aggregated by colour.

Automated test procedure. The test procedure runs a configurable number of consecutive scramble-and-solve cycles, recording the success or failure of each attempt along with timing data. This lets the reliability and performance of the system to be measured systematically and provides the data presented in Chapter 6.

## 5.7 Automated Test Procedure

The automatic test GUI App.tester() (Appendix A) function performs a configurable number of consecutive scramble-and-solve cycles, with each cycle consisting of a random scramble executed on the physical robot followed by an attempt to detect, solve, and execute a solution. The scrambles are generated using cubescrambler [20], which produces sequences conforming to the WCA regulations for competition scrambles. For each cycle, the function records the success or failure of the attempt, the time spent in colour detection and solver invocation, and the time taken to execute the solve.

## 6 Testing and Validation

This chapter documents the automated testing performed on the completed system and presents the results.

## 6.1 Testing Methodology

Each test run consists of a sequence of independent scramble-and-solve cycles. For each cycle it generates a WCA-compliant random scramble using cubescrambler [20], executes it on the physical robot, captures fresh images from both cameras, and attempts to construct a valid cubestring. If the resulting cubestring fails the solver’s validity check, the single-error correction routine described in Section 5.5 is applied. If the cubestring still cannot be solved – it captures new images from both cameras and repeats the process, up to a maximum of 200 attempts. If a solution is found within the attempt limit, the move sequence is sent to the Arduino and the solve time is recorded. If no solution is found within 200 attempts, the cycle is recorded as a failure.

A “failure” in this testing context means that the colour detection stage couldn’t produce a recoverable cubestring within 200 fresh image captures, not that the robot crashed or experienced a mechanical or software fault. Each cycle records the scramble sequence, the solution sequence, success/failure, the total solve time, the number of detection attempts required, the move count produced by the solver, the equivalent total turn count (where 180° moves are counted as two turns), and the resulting turns per second.

## 6.2 Test Configuration

Two formal test runs of 100 cycles each were performed. Both runs used identical conditions, with the system at its highest reliable operating speed: 100% speed (320µs step delay) and a move delay of 0ms. These values were arrived at through informal testing before the formal runs. At step delays shorter than 320µs, the motors occasionally lose synchronisation under load and produce inaccurate rotations. The 0ms inter-move delay caused no observable instability and so was kept for maximum speed. The system drew approximately 3A on average from the 14V supply during these runs. The 4.8A current limit on the bench supply was not approached at any point.

## 6.3 Results

Both tests achieved a 100% success rate over their 100 cycles, with no failures observed in either run. Aggregated statistics are shown below:

Metric | Test Run 1 (Appendix K) | Test Run 2
Cycles completed | 100 | 100
Successful solves | 100 | 100
Success rate | 100 % | 100 %
Mean solve time (s) | 2.117 | 2.146
Fastest solve time (s) | 1.500 | 1.781
Slowest solve time (s) | 4.250 | 5.343
Mean move count | 19.68 | 19.93
Mean turn count | 28.66 | 28.95
Mean turns per second | 15.35 | 15.35
Mean detection attempts | 2.94 | 4.37

First-attempt successes | 70 | 68
Table 1. Aggregated test results

The two runs produced very similar results across all metrics, giving confidence that the figures observed are representative of the system’s normal behaviour rather than artefacts of a single favourable run.

Solve times. The mean solve time across both runs is just above 2.1 seconds, with the fastest single solve at 1.5 seconds. For comparison, the current human world record for solving a 3×3×3 Rubik’s Cube is 2.76 seconds, set by Teodor Zajder in 2026; the system therefore comfortably beats human capability under typical conditions. The slowest solves in each run (4.250 seconds and 5.343 seconds) correspond to cycles where colour detection needed a lot of fresh image captures before producing a valid cubestring, not to genuinely slow physical execution.

Move efficiency. The Kociemba two-phase algorithm consistently produces near-optimal solutions, with mean move counts of 19.68 and 19.93 across the two runs and a maximum of 22 in any single solve. This is close to the theoretical upper bound of 20 moves for any scramble [22], recognising that the solver is given a finite 0.1 second budget per attempt and so doesn’t always reach the optimum. The mean turn count is around 28.8, reflecting that about 9 of the average 19.8 moves in each solution are 180° rotations. The fastest solve at 1.5 seconds corresponded to a solution with a particularly low turn count.

Mechanical performance. The mean turns-per-second figure of 15.35 was identical across both runs, showing that the motor control subsystem performs deterministically. A turn rate of 15.35 TPS corresponds to a per-turn duration of about 65 ms, which matches the expected value derived from the firmware configuration: at a step delay of 320 µs, each step pulse takes 640 µs, and 100 steps are required per 90° rotation, giving a calculated 64 ms per turn. The small discrepancy is attributable to per-move overhead in the firmware loop. No mechanical failures (jams, missed steps, or coupler slippage) were observed at any point during either run.

## 6.4 Time Budget Breakdown

To understand where time is spent during a typical solve, the contributions of each stage were estimated from the test data. With a mean solve time of around 2.13 s and a mean turn count of 28.8 at 15.35 TPS, motor execution accounts for around 1.88 s of each cycle. The remaining 0.25 seconds is taken up by colour detection and solver invocation. Colour detection alone takes up the majority of that time. The system spends around 90% of each cycle executing physical moves and around 10% on all software processing combined. This breakdown was consistent across both runs and confirms that further reductions in solve time will require improvements to the mechanical execution stage rather than to the software pipeline.

## 6.5 Detection Reliability

The number of detection attempts required per solve is the most variable metric and is worth examining more closely. The distribution of attempts per cycle across both runs is shown:

Attempts required | Run 1 | Run 2
1 (first-attempt success) | 70 | 68
2 to 5 | 22 | 20
6 to 20 | 5 | 8
21 to 50 | 1 | 2
Greater than 50 | 1 | 2
Maximum observed | 75 | 114
Table 2. Distribution of attempts per cycle per test run

In both runs, around 70 of 100 cycles were solved on the first attempt, meaning the colour detection produced a directly valid cubestring (or one repairable by single-error correction) in the majority of cases. A further 20-22 cycles were resolved within five attempts, and only a small number of outliers required substantially more. The maximum observed attempt count was 114, well within the 200-attempt limit; no cycle in either run reached the failure threshold.

The cycles that required many attempts correspond to scrambles in which one or more facelets produce HSV values close to the boundary between two adjacent colour classes – typically between red and orange, between yellow and green, or between white and blue. The small frame-to-frame variation in HSV values from the cameras’ sensor noise causes these facelets to flicker between two classifications across successive samples. The detection strategy relies on this flicker eventually resolving to a sample in which all flickering facelets simultaneously land on classifications that produce a valid cubestring. This approach is not fool-proof but significantly increases the success rate on borderline cases.

## 6.6 Reliability Estimate

The 200 cycles documented in this chapter all succeeded, which corresponds to an observed success rate of 100% within the formal testing. However, some informal testing identified specific scramble configurations that the system can’t solve – typically those with multiple borderline facelets simultaneously, exceeding the recoverable error count even after many attempts. Based on this informal testing, the overall reliability is conservatively estimated at approximately 99%, with the remaining ~1% failure rate attributable entirely to the colour detection stage rather than to mechanical or software faults.

## 6.7 Limitations Identified

Lighting sensitivity. The colour detection pipeline depends heavily on the lighting environment. Although the supplementary LEDs provide stable, uniform illumination under normal conditions, any change to the ambient lighting, i.e. a curtain being drawn, a cloud passing the window, or a light being switched on, measurably shifts the HSV values of all facelets. This is a fundamental limitation of any HSV-thresholded colour detection approach.

Inability to verify executed moves. The Arduino firmware drives the stepper motors in open loop, with no feedback on whether each step actually produced the corresponding physical rotation. If a motor were to lose synchronisation mid-solve, which is possible at higher speeds, the system would have no way to detect the failure.

Single-error correction limit. The error correction routine can only handle cubestrings with a single misclassification at a time. The small number of scrambles the system can’t solve are typically those with multiple borderline facelets that fail to resolve onto a single-error-correctable state across all 200 attempts. A multi-error correction strategy could solve more of these, but at substantially higher computational cost per attempt.

## 7 Conclusions and Future Work

This final chapter draws together the work documented in the preceding chapters, evaluates the project against its objectives, and identifies the most significant opportunities for future improvement.

## 7.1 Project Outcome

Measured against the objectives set out in Chapter 1, the project has been a success. A robust mechanical frame holding six stepper motors was designed and 3D-printed; accurate and reliable stepper motor control was implemented in firmware on an Arduino Nano; a computer vision pipeline capable of detecting the colour of each visible facelet and reconstructing the obscured ones was developed; the Kociemba two-phase solving algorithm was integrated and its output translated into executable motor commands; a graphical user interface was built around the system to support operation, calibration, and automated testing; and all of these subsystems were combined into a working autonomous robotic system.

The completed system achieves a mean solve time of approximately 2.13 seconds, with a fastest recorded solve of 1.5 seconds. Across 200 documented test cycles, every cycle was solved successfully. Informal testing identified a small number of scramble configurations that the system cannot solve, all of which fail at the colour detection stage rather than through any mechanical or software fault; the overall reliability is conservatively estimated at approximately 99%. A user can scramble a cube by hand, insert it into the robot in the marked orientation, press a single button, and have the robot solve it in less than the current human world record time of 2.76 seconds.

## 7.2 Critical Reflection

While the project achieved its objectives, there’s significant scope for improvement in nearly every subsystem. However, many of the improvements identified below were only recognisable in hindsight, problems that could not have been easily anticipated from the outset.

Lessons learned. Several broad observations came out of completing the project. Firstly, iterative prototyping was essential. The motor coupler design went through nine iterations before achieving a satisfactory fit, and the side-mount design had to be reworked entirely after the first single-piece print failed structurally along its layer lines. Neither problem was foreseeable from CAD alone. Secondly, empirical tuning was unavoidable in several places. The HSV classification values, the maximum reliable step rate, and the inter-move delay were all arrived at through testing rather than from first principles. Thirdly, using an established open-source library for the cube-solving algorithm yielded much more value than writing a custom implementation would have. Using the existing Python implementation let the project focus on integration challenges rather than algorithm development. Finally, splitting the work between a host computer and a microcontroller proved correct in retrospect: each device handles the work it’s best suited to.

Project management. With more formal project planning at the start progress would likely have been smoother. In practice, several stages of the project hit unanticipated obstacles that took more time than initially estimated. The colour detection stage in particular went through multiple iterations: the migration from RGB to HSV, the switch from rectangular sampling regions to perspective-projected quadrilaterals, and the development of the error correction process. Each refinement was driven by empirical observations that only became visible after the previous version was implemented. While many of these unknowns were genuinely difficult to predict, more formal planning would at least have given clearer visibility of where the project stood relative to its overall timeline.

## 7.3 Future Work

Many opportunities for further development have been identified, both during the build and through later testing.

Mechanical refinements. The mechanical frame is functional but would benefit from a refined design that simplifies cube insertion. The current process is workable but awkward, and it is easy to accidentally shift the cameras during insertion. A revised frame in which the cube can be inserted through an easier process and one in which the cameras are more rigidly fixed to the frame would address both issues. Moving the entire assembly to a more permanent enclosure, ideally with an integrated LCD display and physical button controls in addition to the existing software interface, would make the system more presentable and easier to operate without a connected computer.

Motor and driver improvements. The choice of stepper motors was deliberate and appropriate for a first-generation system, but the per-turn duration is the dominant component of the total solve time. Replacing the steppers with brushless DC motors with encoders, would allow significantly higher rotation speeds at the cost of much more control complexity. As an interim improvement, implementing acceleration ramping in the firmware would allow higher peak step rates than the current constant-speed profile without requiring different motor hardware. Activating each driver one-by-one, rather than all at once, would reduce the inrush current peak and allow a lower, safer current limit.

Power supply. The current dependency on a bulky bench power supply and a separate battery pack is a practical inconvenience and limits portability. A purpose-selected fixed-voltage 14V supply with a sufficient current, combined with a properly working 6V rail derived from the same supply using a buck converter, would replace both the bench supply and the battery pack with a single neat solution.

Custom electronics. The current breadboard / protoboard assembly is appropriate for prototyping but is fragile and visually untidy. A custom PCB hosting the Arduino, the six stepper motor drivers, the supplementary lighting connections, and the buck converter would substantially reduce the wiring footprint, improve electrical reliability, and produce a more professional finished system.

Migration to a Raspberry Pi. The host software is currently run on a Windows PC or laptop. Moving it to a Raspberry Pi was attempted during the project but was not completed: the cameras and the Pi together drew enough current that the Pi would intermittently shut down, and additional integration issues with the UI and camera handling under the Pi’s environment were not resolved within the project timeline. A future revision could pursue this with an appropriate power supply and time set aside for the necessary debugging. A successful Pi deployment would let the system run as a self-contained appliance rather than depending on a connected PC.

Vision system. The most significant improvement opportunity in the entire system is the vision subsystem. The chosen Trust Spotlight Pro webcams are inexpensive but produce relatively dim, low-exposure images that need aggressive contrast normalisation in software. Higher-resolution cameras with greater dynamic range, faster frame rates, and better low-light performance would substantially reduce noise. The supplementary lighting could also be redesigned to produce more uniform illumination across all visible facelets. Independent HSV ranges per facelet, rather than the global ranges currently in use, would directly address the issue of facelets at different camera angles producing systematically different HSV values for the same physical colour. Finally, the calibration and quadrilateral placement steps could be automated entirely through image analysis by analysing the cube boundaries, detecting the individual facelet sampling regions, and deriving the colour ranges automatically

Software refinements. The host-side codebase reached a working state but would benefit from substantial refactoring. The user interface in particular has grown organically and would be cleaner if redesigned around a more structured architecture. Several features remain partially implemented or absent: writing the calibration output directly to the JSON configuration file rather than reporting it to the operator, displaying the move count alongside the solve timer, and exposing additional diagnostic information during automated test runs. A multi-error correction strategy could help solve the small number of scrambles that currently exceed the system’s recovery capability.

## 7.4 Closing Remarks

The project’s value lies primarily in its educational and demonstrative dimensions. As a personal undertaking, it required integrating mechanical design, electronics, embedded firmware, computer vision, and host-side software into a single coherent system, and produced substantial learning across all of these areas. As a finished robot, the system is a tangible demonstration of what’s achievable with accessible hardware and freely available software libraries, and provides a platform on which any of the future improvements identified above could be explored. While the robot isn’t, in any practical sense, a useful product to the wider world, projects like this have continuing value as platforms for engineering education and as accessible demonstrations of integrated robotics for outreach to students considering technical disciplines.

The completed system has been built, tested, and shown to perform reliably against its objectives. The remaining opportunities for improvement are extensive but well-understood, and stand as a record of the engineering judgement gained through building the system in the first place.

## 8 References

[1] D. Dorran, “Report Template and Guide to Writing Style”. Accessed on: Jan. 25, 2020.
| [Online]. Available: http://eleceng.tudublin.ie/dorran/report_info/. [Accessed: Apr- 2026].
[2] M. Farrell, “Masters in Advanced Engineering Project Marking Scheme and
| Guidelines”, Dublin Institute of Technology, Dublin, Ireland, March 2008.
[3] “Kociemba’s Algorithm,” SpeedSolving Wiki. [Online]. Available:
| https://www.speedsolving.com/wiki/index.php/Kociemba%27s_Algorithm. [Accessed: Apr-2026].
[4] H. Kociemba, “RubiksCube-TwophaseSolver,” GitHub. [Online]. Available:
| https://github.com/hkociemba/RubiksCube-TwophaseSolver. [Accessed: Apr-2026].
[5] Stevan Kostoski, “From zero to Rubik’s Cube solving robot,” Medium. [Online].
| Available: https://stevcooo.medium.com/from-zero-to-rubiks-cube-solving-robot- ad3a2838cd. (https://stevcooo.medium.com/from-zero-to-rubiks-cube-solving-robot-ad3a2838cd) [Accessed: Apr-2026].
[6] Aaed Musa, “Rubik’s Cube Solver,” Hackaday.io. [Online]. Available:
| https://hackaday.io/project/190071-rubiks-cube-solver. [Accessed: Apr-2026].
[7] Aaed Musa, “I Built a Rubik’s Cube Solver,” YouTube, Jan. 7, 2022. [Video].
| Available: https://youtu.be/V8gHTKWw--Y. [Accessed: Apr-2026].
[8] Jay Flatland, “World’s Fastest Rubik’s Cube Solving Robot,” YouTube, Nov. 15, 2023.
| [Video]. Available: https://youtu.be/ixTddQQ2Hs4. [Accessed: Apr-2026].
[9] “CUBOTino, the Rubik’s Cube solving robot,” Raspberry Pi, [Online]. Available:
| https://www.raspberrypi.com/news/cubotino-the-rubiks-cube-solving-robot/. [Accessed: Apr-2026].
[10] HiDe Tech, “dual Axis Rubik’s cube solving robot (Arduino/Processing),” YouTube,
| Jan. 12, 2021. [Video]. Available: https://www.youtube.com/watch?v=o- auWQzWKxM. (https://www.youtube.com/watch?v=o-auWQzWKxM) [Accessed: Apr-2026].
[11] Aaed Musa, “I Built a Rubik’s Cube Solving Robot,” YouTube, Dec. 1, 2023. [Video].
| Available: https://www.youtube.com/watch?v=m0bMMALYMYk. [Accessed: Apr- 2026].

[12] Handsontec, “17HS4401S 1.7A Torque: 43N.cm Stepper Motor,” Datasheet. [Online].

Available: https://www.handsontec.com/dataspecs/17HS4401S.pdf. [Accessed: May-

2026].

[13] Trinamic Motion Control GmbH & Co. KG, “TMC2202, TMC2208, TMC2224

Datasheet,” Rev. 1.14, Feb. 2023. [Online]. Available:

https://www.analog.com/media/en/technical-documentation/data-

sheets/TMC2202_TMC2208_TMC2224_datasheet_rev1.14.pdf. (https://www.analog.com/media/en/technical-documentation/data-sheets/TMC2202_TMC2208_TMC2224_datasheet_rev1.14.pdf) [Accessed:May-2026].

[14] Allegro MicroSystems, “A4988: DMOS Microstepping Driver with Translator and

Overcurrent Protection,” Datasheet. [Online]. Available:

https://www.pololu.com/file/0j450/a4988_dmos_microstepping_driver_with_translator.

pdf. (https://www.pololu.com/file/0j450/a4988_dmos_microstepping_driver_with_translator.pdf) [Accessed: May-2026].

[15] Arduino, “Arduino Nano.” [Online]. Available: https://docs.arduino.cc/hardware/nano/.

[Accessed: May-2026].

[16] OpenCV, “opencv-python,” GitHub. [Online]. Available:

https://github.com/opencv/opencv-python. [Accessed: May-2026].

[17] T. Schimansky, “CustomTkinter.” [Online]. Available:

https://customtkinter.tomschimansky.com. [Accessed: May-2026].

[18] C. Liechti, “pyserial,” GitHub. [Online]. Available:

https://github.com/pyserial/pyserial. [Accessed: May-2026].

[19] T. Rinca, “magiccube,” GitHub. [Online]. Available:

https://github.com/trincaog/magiccube. [Accessed: May-2026].

[20] koma52, “cubescrambler,” GitHub. [Online]. Available:

https://github.com/koma52/cubescrambler. [Accessed: May-2026].

[21] D. Singmaster, Notes on Rubik’s Magic Cube. NJ, USA: Enslow Publishers, 1981.
[22] T. Rokicki, H. Kociemba, M. Davidson, and J. Dethridge, “The Diameter of the

Rubik’s Cube Group is Twenty,” SIAM Journal on Discrete Mathematics, vol. 27, no.

2, pp. 1082–1105, 2013.

[23] World Cube Association, “WCA Official Results – Records.” [Online]. Available:

https://www.worldcubeassociation.org/results/records?show=mixed. [Accessed: May-

2026].

[24] Engineers Ireland, “Code of Ethics.” [Online]. Available:

https://www.engineersireland.ie/Professionals/News-Insights/Resource-centre/Member-

resources/Code-of-ethics. (https://www.engineersireland.ie/Professionals/News-Insights/Resource-centre/Member-resources/Code-of-ethics) [Accessed: May-2026].

[25] United Nations, “Goal 4: Ensure inclusive and equitable quality education and promote
lifelong | learning | opportunities | for | all.” | [Online]. | Available:

https://sdgs.un.org/goals/goal4. [Accessed: May-2026].

## 9 Appendices Appendix A. Project Repository and Demo Video

The complete source code, 3D model files, test data, and supporting documentation for this project are hosted publicly on GitHub: https://github.com/PeterMyler/CubeRobot

The Python source code consists of over 1,100 lines so not all of it is included in the appendix.

A demo video of the working project can be viewed here: https://youtu.be/nHWHOQfeOHc
| Appendix B. Singmaster Notation
Singmaster notation is the universal standard language used to write sequences of moves (algorithms) on a Rubik's Cube.

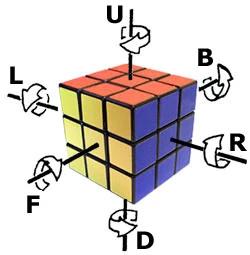
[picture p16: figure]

## Appendix C. Bill of Materials

System Component | Cost
6x NEMA 17HS4401 Stepper Motors | €60
6x TMC2208 Stepper Motor Drivers | €20
2x Trust Light Pro USB Webcams | €15
Arduino Nano | previously purchased
4x white LEDs | previously purchased
4xAA batteries & battery holder | previously purchased
MoYu RS3M 2020 Speed Cube | previously purchased (€15)
NANKADF WPS3010H variable bench power supply | previously purchased (€60)

Extra Materials and Consumables:
- 3D printer filament (~300g)
- M3 nuts and bolts
- Wires and connectors
- Protoboards and breadboard
- Solder and flux
- Lots of time (€∞)

## Appendix D. Top camera facelet order

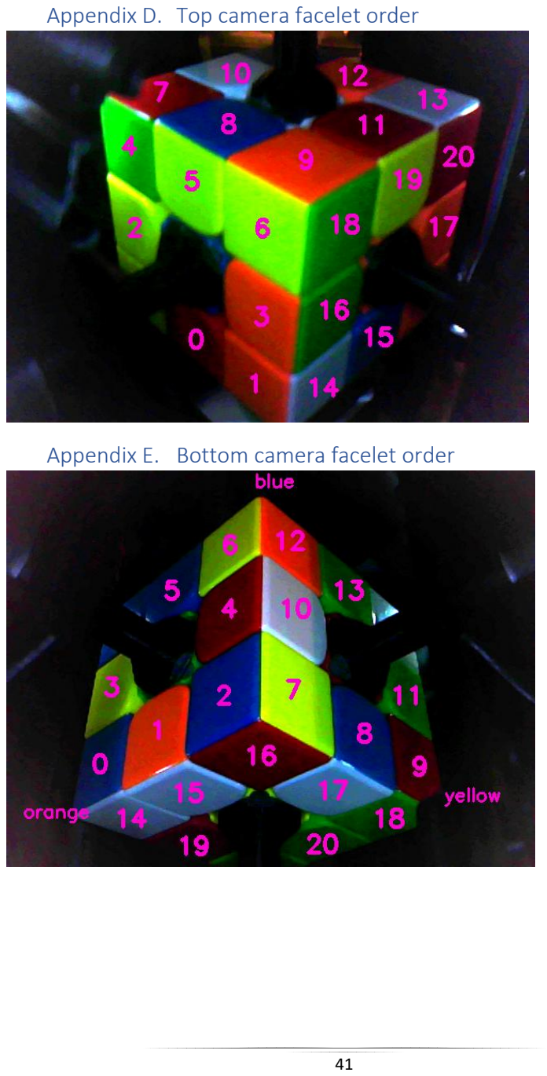
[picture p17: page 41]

## Appendix E. Bottom camera facelet order

## Appendix F. TwophaseSolver Cube Notation

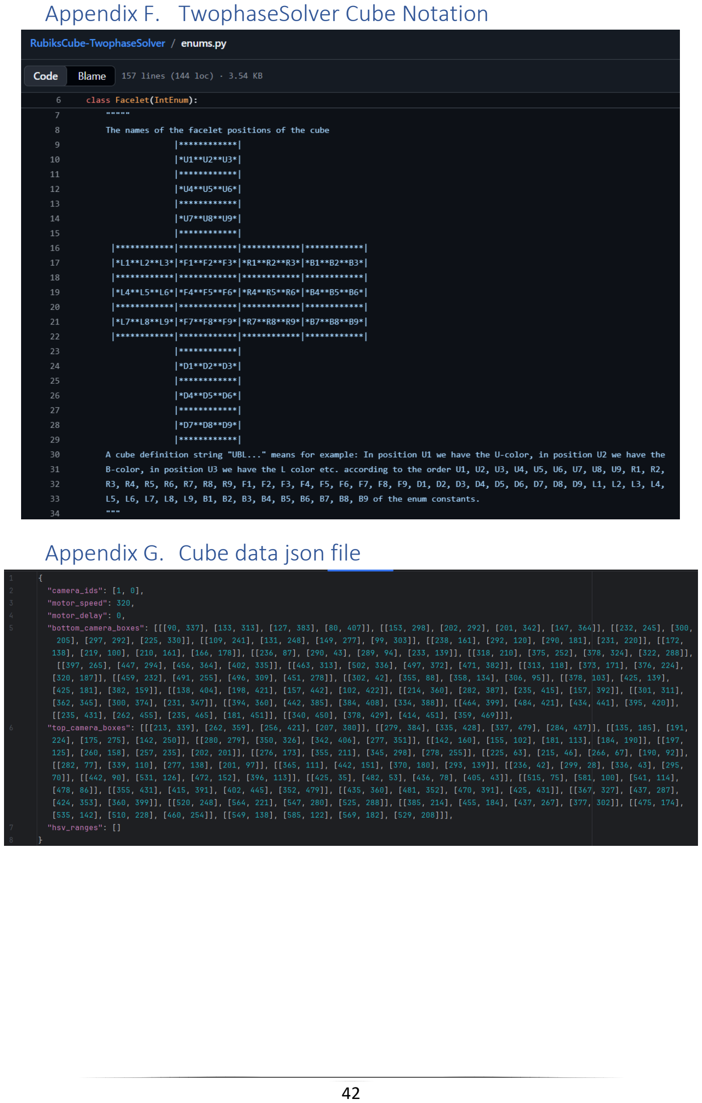
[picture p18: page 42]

## Appendix G. Cube data json file

## Appendix H. Camera.py

## Appendix H-1. Camera class init

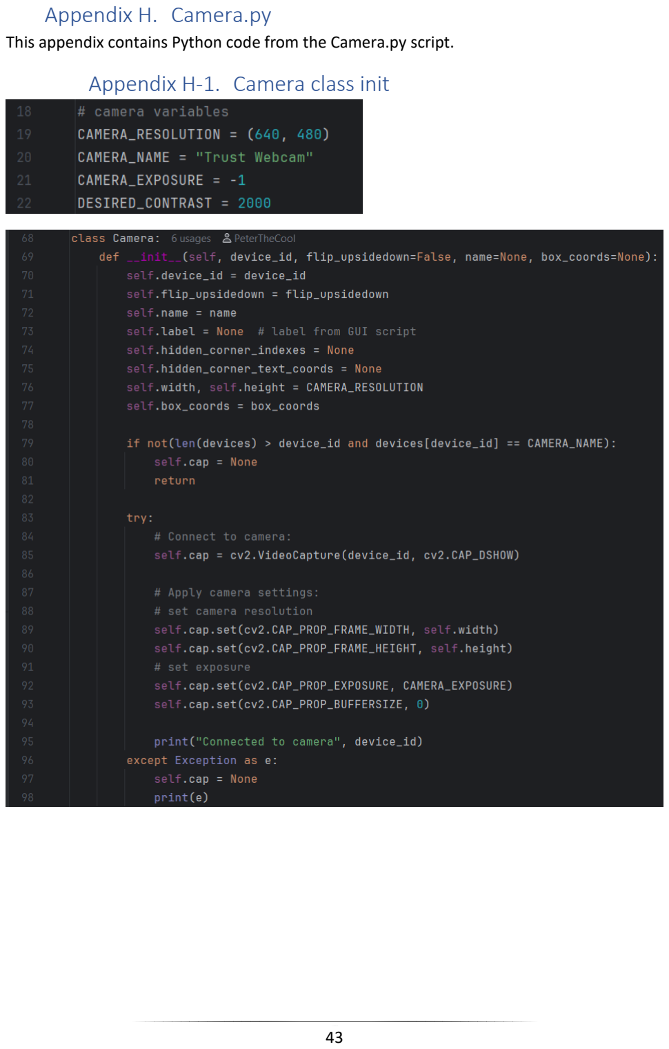
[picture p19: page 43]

This appendix contains Python code from the Camera.py script.

## Appendix H-2. Camera frame handling

## Appendix H-3. HSV colour classification values

## Appendix H-4. HSV colour classification function

## Appendix H-5. Hidden corner piece colours

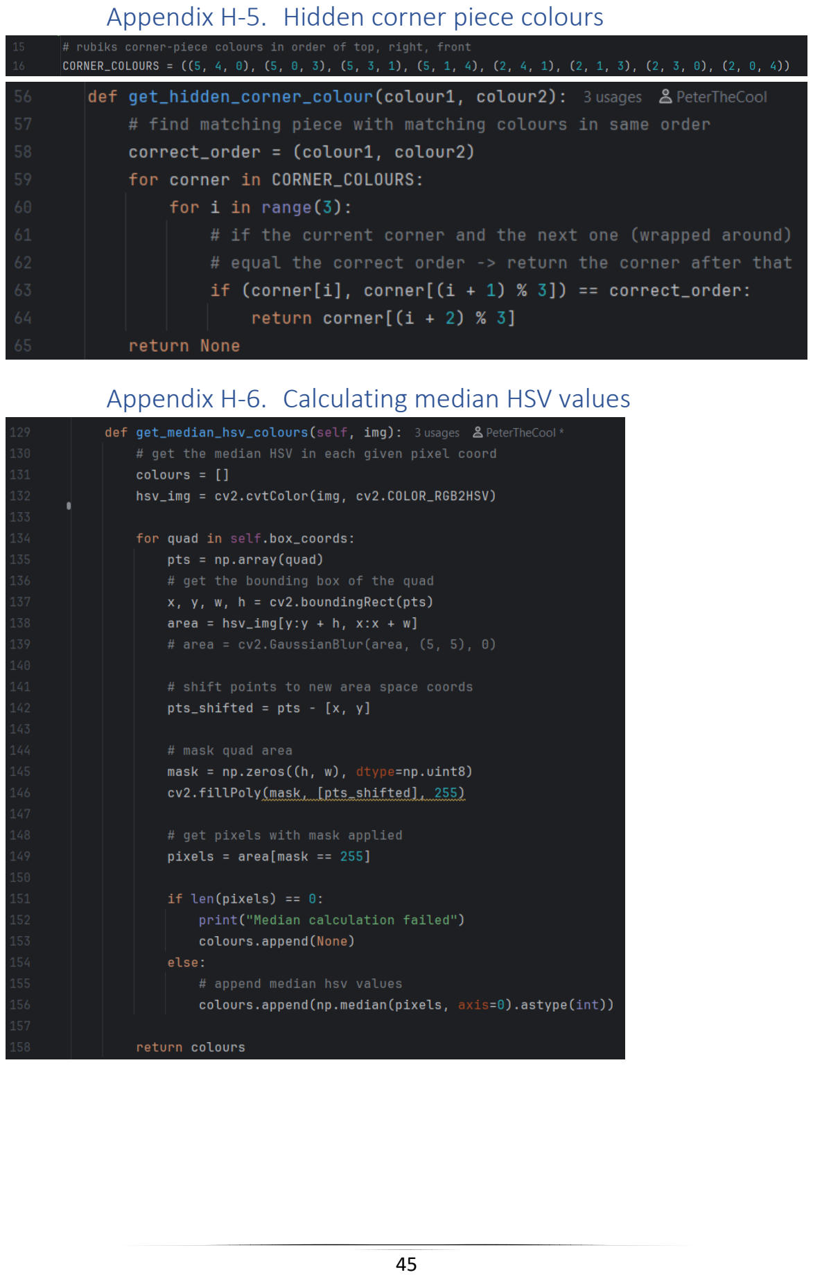
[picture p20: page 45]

## Appendix H-6. Calculating median HSV values

## Appendix I. Cube.py

## Appendix I-1. Cube class init

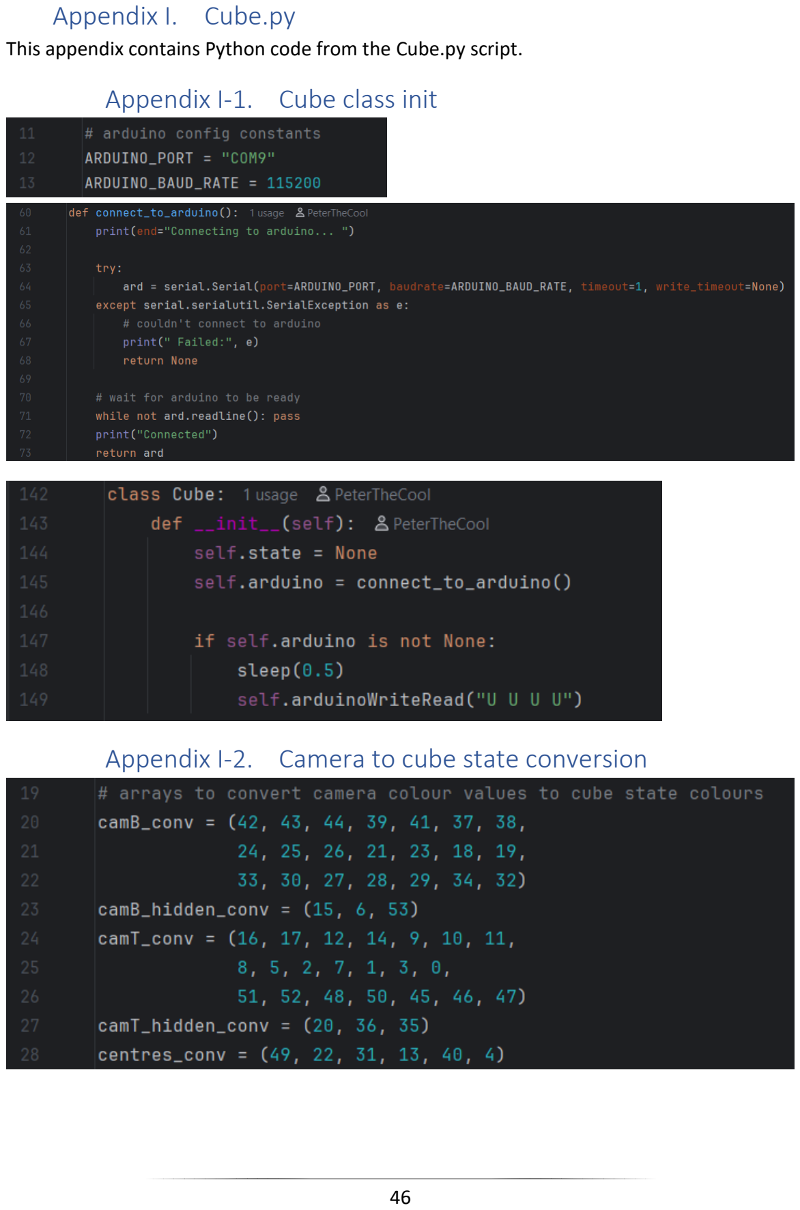
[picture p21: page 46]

This appendix contains Python code from the Cube.py script.

## Appendix I-2. Camera to cube state conversion

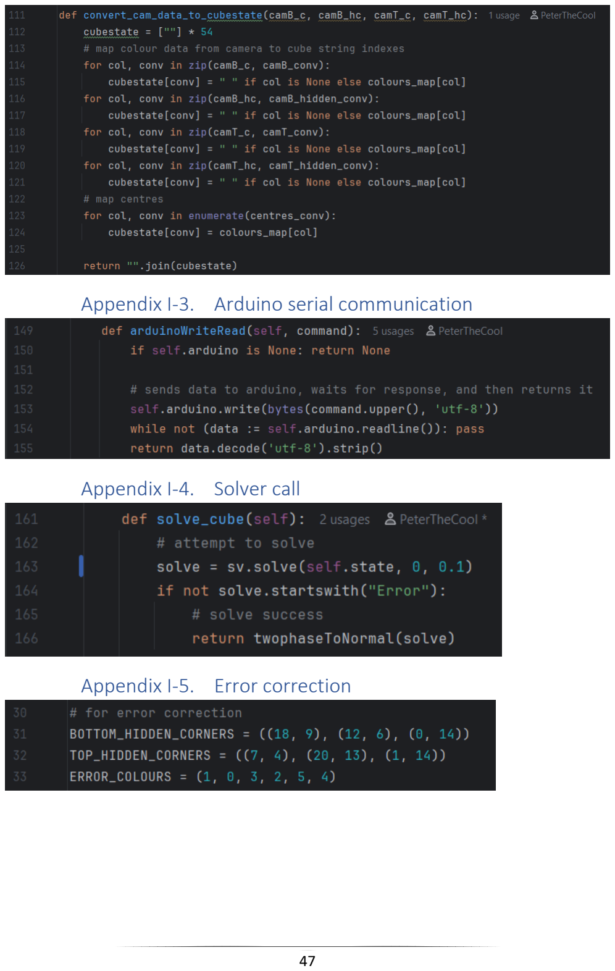
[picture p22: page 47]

## Appendix I-3. Arduino serial communication

## Appendix I-4. Solver call

## Appendix I-5. Error correction

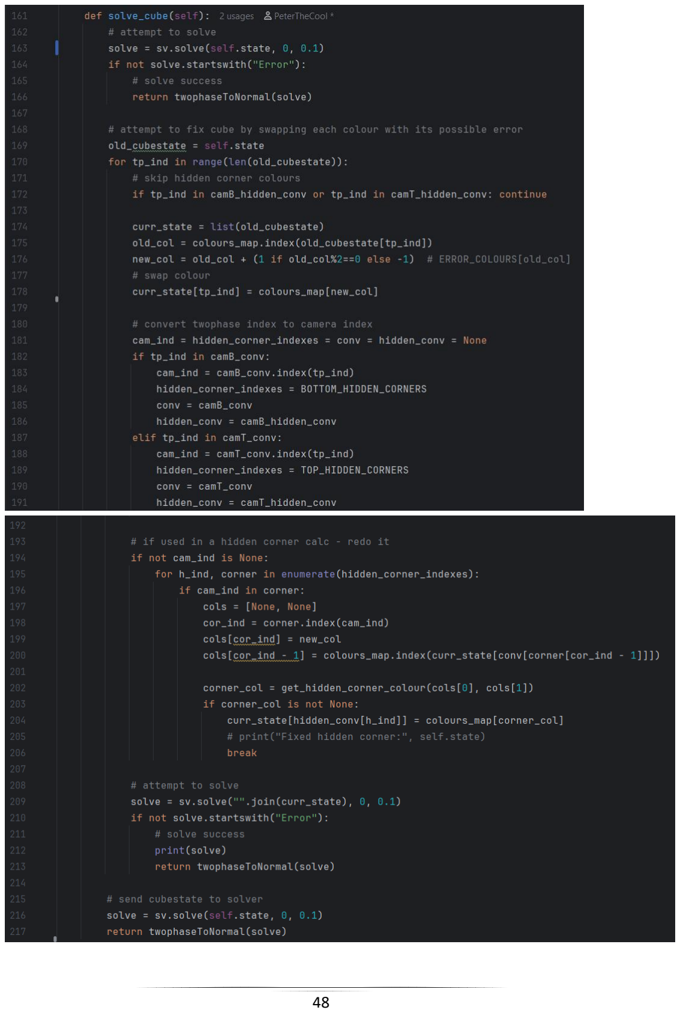
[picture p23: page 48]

## Appendix J. GUI.py Appendix J-1. Implementing the Camera class

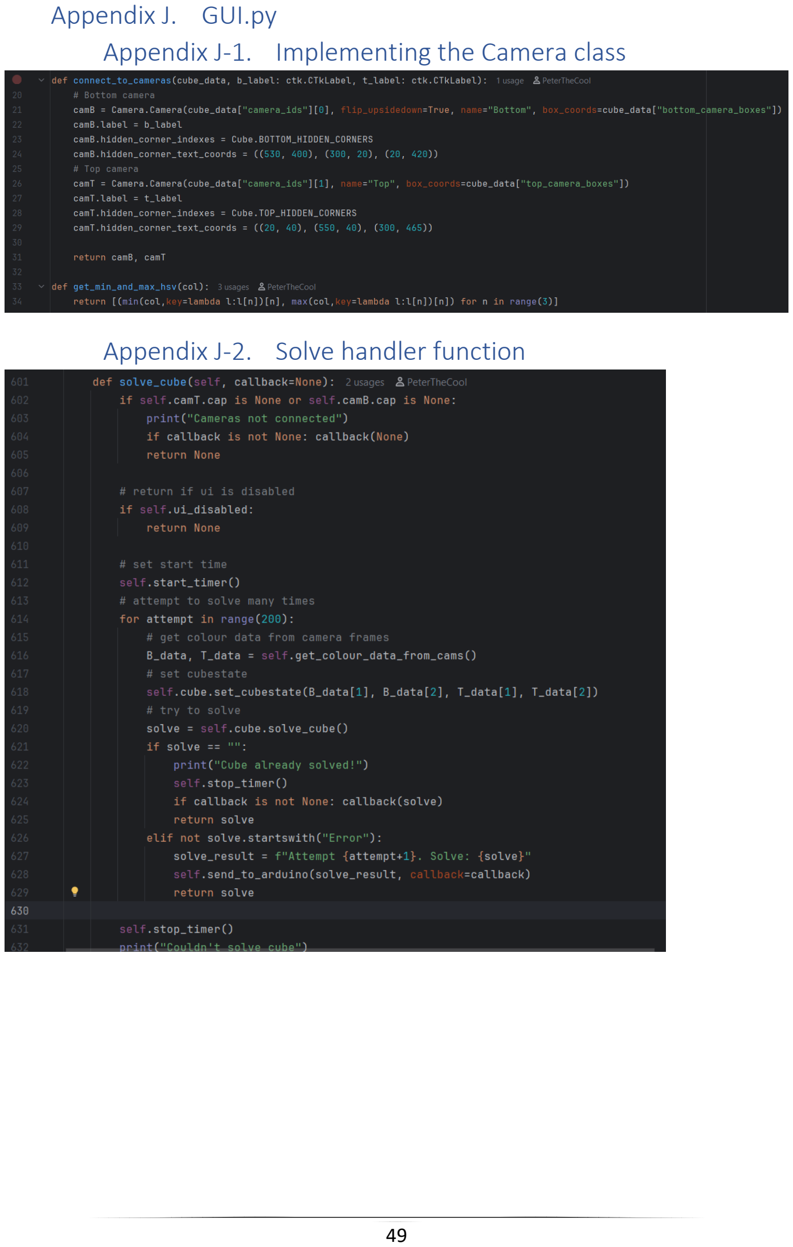
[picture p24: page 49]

## Appendix J-2. Solve handler function

## Appendix K. Test 1

Tests 15-81 were hidden for the purposes for taking this image. The full data can be found in the Test_1.csv file in the GitHub repository.

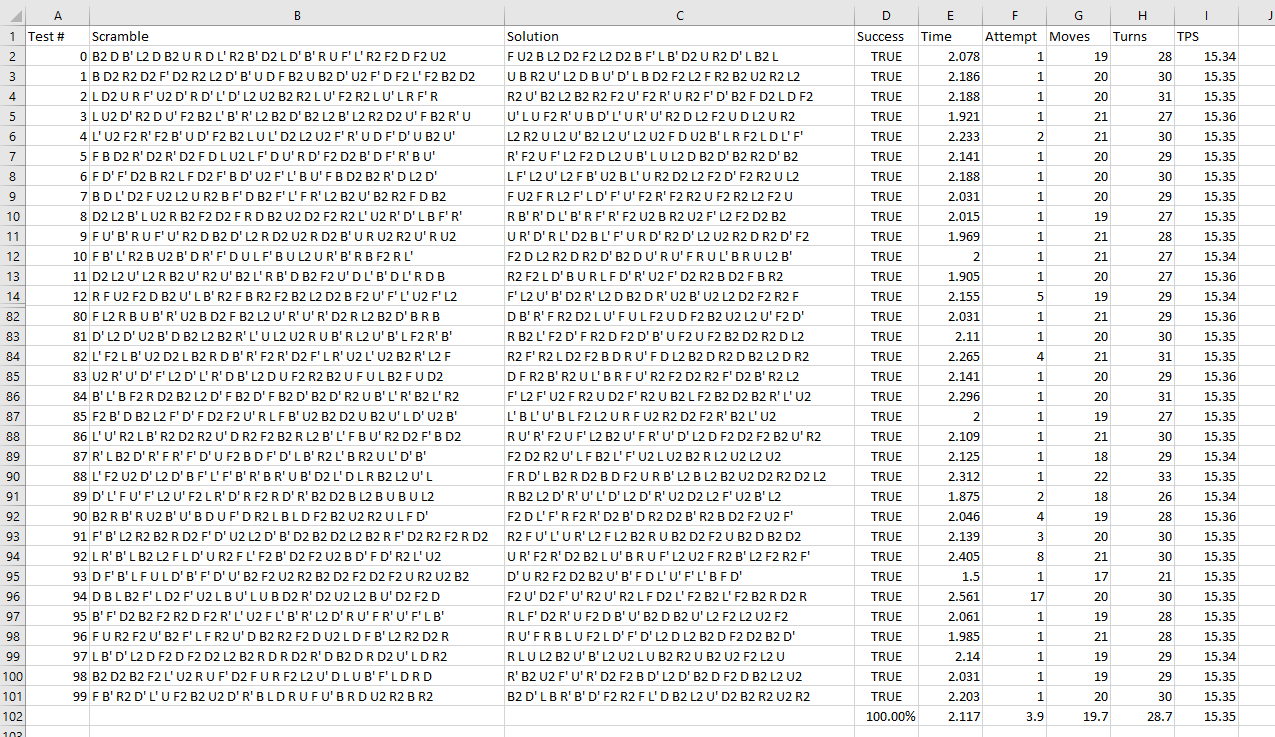
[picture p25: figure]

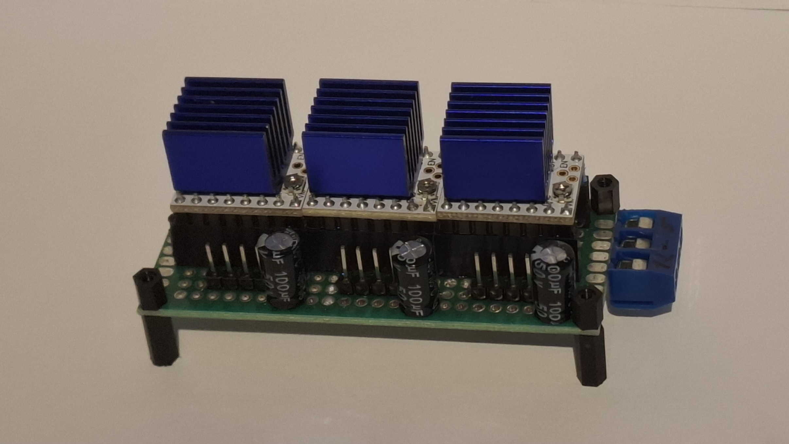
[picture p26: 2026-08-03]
images/drivers_board.jpg

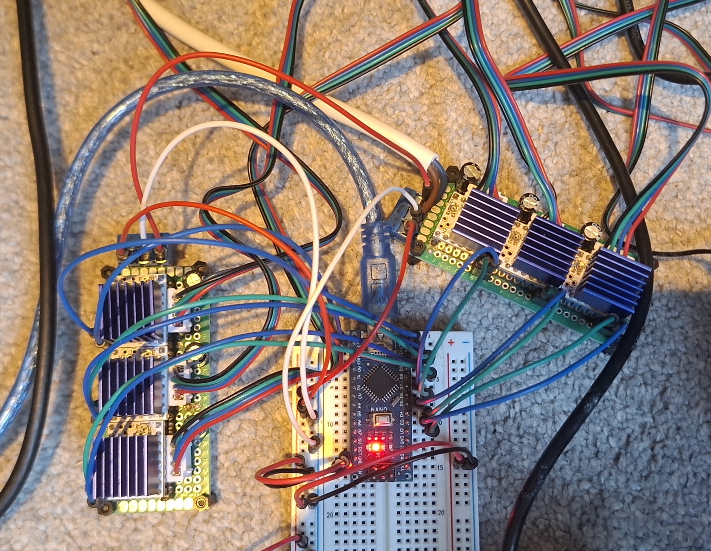
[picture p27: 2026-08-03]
images/arduino_and_drivers.jpg

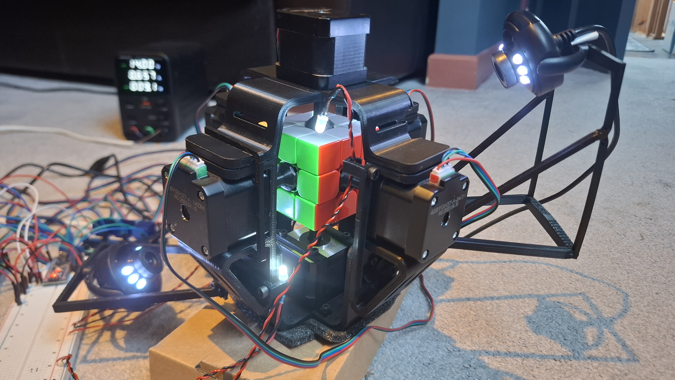
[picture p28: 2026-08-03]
images/frame_with_cube.jpg

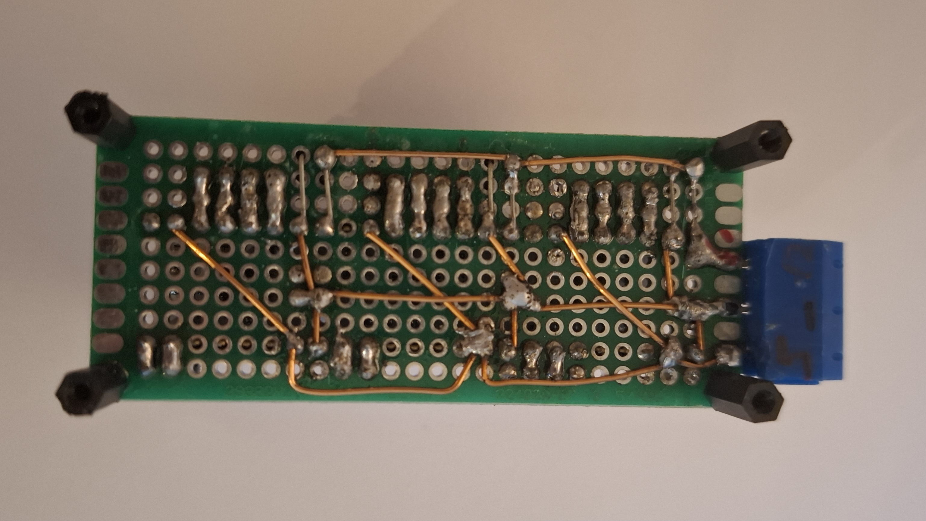
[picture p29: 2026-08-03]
images/drivers_board_underside.jpg

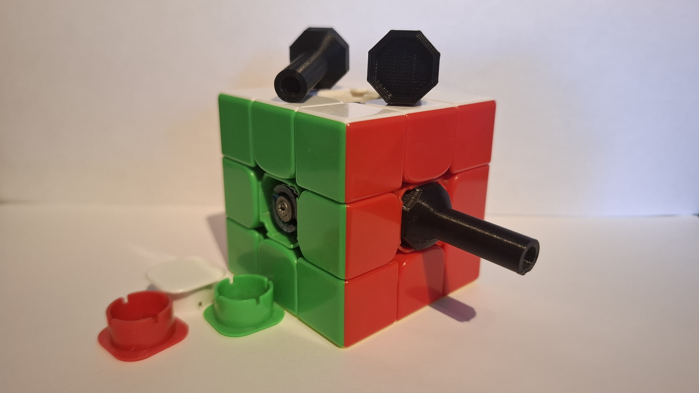
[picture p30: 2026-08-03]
images/cube_and_couplers.jpg

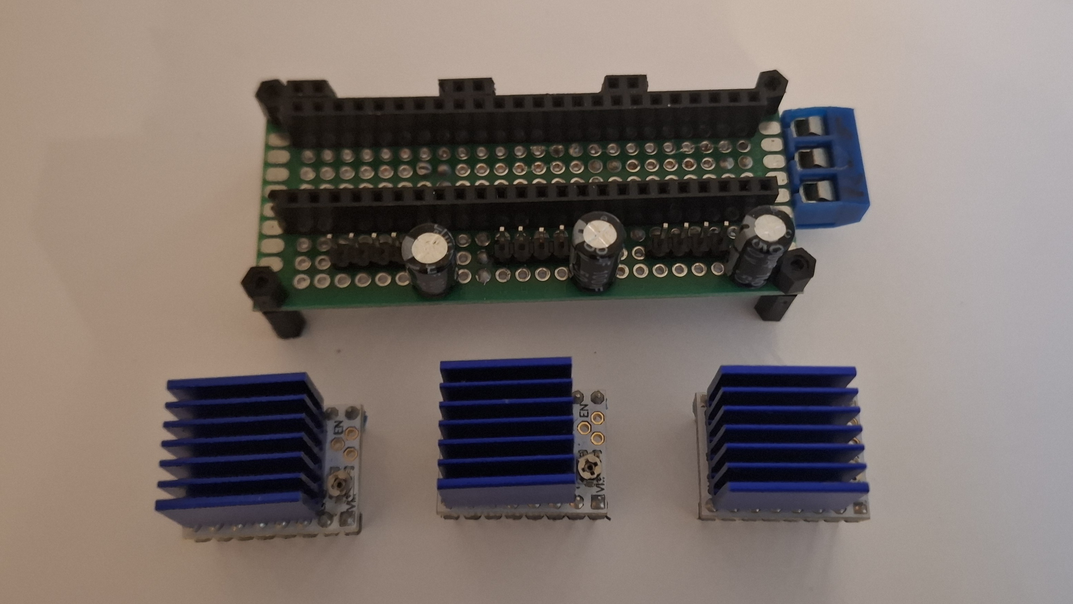
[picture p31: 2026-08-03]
images/drivers_and_board.jpg

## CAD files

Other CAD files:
cad/Full_Cube_Robot.f3d

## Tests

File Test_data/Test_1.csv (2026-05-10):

Test # | Scramble | Solution | Success | Time | Attempt | Moves | Turns | TPS
0 | B2 D B' L2 D B2 U R D L' R2 B' D2 L D' B' R U F' L' R2 F2 D F2 U2 | F U2 B L2 D2 F2 L2 D2 B F' L B' D2 U R2 D' L B2 L | TRUE | 2.078 | 1 | 19 | 28 | 15.34
1 | B D2 R2 D2 F' D2 R2 L2 D' B' U D F B2 U B2 D' U2 F' D F2 L' F2 B2 D2 | U B R2 U' L2 D B U' D' L B D2 F2 L2 F R2 B2 U2 R2 L2 | TRUE | 2.186 | 1 | 20 | 30 | 15.35
2 | L D2 U R F' U2 D' R D' L' D' L2 U2 B2 R2 L U' F2 R2 L U' L R F' R | R2 U' B2 L2 B2 R2 F2 U' F2 R' U R2 F' D' B2 F D2 L D F2 | TRUE | 2.188 | 1 | 20 | 31 | 15.35
3 | L U2 D' R2 D U' F2 B2 L' B' R' L2 B2 D' B2 L2 B' L2 R2 D2 U' F B2 R' U | U' L U F2 R' U B D' L' U R' U' R2 D L2 F2 U D L2 U R2 | TRUE | 1.921 | 1 | 21 | 27 | 15.36
4 | L' U2 F2 R' F2 B' U D' F2 B2 L U L' D2 L2 U2 F' R' U D F' D' U B2 U' | L2 R2 U L2 U' B2 L2 U' L2 U2 F D U2 B' L R F2 L D L' F' | TRUE | 2.233 | 2 | 21 | 30 | 15.35
5 | F B D2 R' D2 R' D2 F D L U2 L F' D U' R D' F2 D2 B' D F' R' B U' | R' F2 U F' L2 F2 D L2 U B' L U L2 D B2 D' B2 R2 D' B2 | TRUE | 2.141 | 1 | 20 | 29 | 15.35
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

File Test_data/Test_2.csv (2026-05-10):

Test # | Scramble | Solution | Success | Time | Attempt | Moves | Turns | TPS
0 | B F U' D' R2 B' R' L' F2 B R F U' B2 R' D F B2 D' F R2 D F D2 R' | F2 R F B' U2 F L' D F' R' B2 L2 B' R2 B' L2 B' L2 | TRUE | 1.858 | 1 | 18 | 25 | 15.35
1 | D B2 F U F2 R2 U B2 U F' R2 L D F B R2 L2 B' F2 U L' B F2 R2 B | F' R' U' R' L2 F U' L' B R' D R' F2 B2 R' D2 R' L F2 L' | TRUE | 1.844 | 1 | 20 | 25 | 15.36
2 | U' L' F' D' R2 D R B D L' B' F' R D' L B' R' F2 U R2 B F' D2 R2 U | D' F2 R' D L F' L B U2 B' R U2 L2 B U2 R2 U2 F2 D2 R2 | TRUE | 2.234 | 6 | 20 | 30 | 15.35
3 | R U2 R2 U2 L' U L' B' L' B2 F L2 B' R2 U2 D F U2 D R2 F L' D L' U2 | R U' R D F R' L' U F2 D R D R2 B2 D2 F2 U2 L2 B2 | TRUE | 1.905 | 2 | 19 | 27 | 15.36
4 | R L F2 L' R2 D B D L' R F B U' D2 L' B2 L F' B L2 U D' R' L2 B2 | R D R F' U' D' L2 F L U B D2 L2 F' D2 R2 L2 B U2 B2 | TRUE | 2.046 | 4 | 20 | 28 | 15.34
5 | D2 F R2 U' B' U D L2 D' U F' B L' U2 F B2 U B' D2 R2 U D' L2 F2 R | R' F2 L' F' B L D2 B L2 U' F R2 U2 D2 F2 D' B2 L2 D F2 | TRUE | 2.156 | 2 | 20 | 30 | 15.35
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

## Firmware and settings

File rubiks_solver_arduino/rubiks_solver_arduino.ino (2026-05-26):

#include <Arduino.h>

//                 motors:     0   1   2   3   4   5
const int motorStepPins[6] = { 2,  4,  6,  8, 10, 12 };
const int motorDirPins[6] =  { 3,  5,  7,  9, 11, 13 };
const int motorNames[6] =   { 'D','F','B','R','L','U' };

int stepDelay = 500;  // delay (us) between each step instruction (330-500+)
int turnDelay = 100;   // delay (ms) bewteen each turn of a motor (0-100+)
int moves = 0;
int extra_moves = 0;

const long BAUD = 115200;


int findName(char ch) {
  for (int i = 0; i < 6; i++) {
    if (ch == motorNames[i]) {
      return i;
    }
  }
  
  return -1;  // couldnt find
}

void executeMove(String move) {
  int motorNum = findName(toupper(move[0]));
  if (motorNum == -1){
    Serial.println("Error! Could not find motor with that name.");
    return;
  }

  int stepP = motorStepPins[motorNum];
  int dirP = motorDirPins[motorNum];

  int steps = 100;
  int dir = 0;

  moves++;

  // set appropriate parameters
  if (move.length() == 2){
    if (move[1] == '2'){
      steps *= 2;
      extra_moves++;
    }
    else {
      dir = 1;
    }
  }

  // execute motor turn
  digitalWrite(dirP, dir);  // dir: 0 = CCW, 1 = CW
  for (int x = 0; x < steps; x++) {
    digitalWrite(stepP, HIGH);
    delayMicroseconds(stepDelay);
    digitalWrite(stepP, LOW);
    delayMicroseconds(stepDelay);
  }

}


void setup() {
  pinMode(A0, OUTPUT);
  digitalWrite(A0, LOW);
  pinMode(A1, OUTPUT);
  digitalWrite(A1, LOW);

  // setup pins
  for (int i : motorStepPins)
    pinMode(i, OUTPUT);

  for (int i : motorDirPins)
    pinMode(i, OUTPUT);


  Serial.begin(BAUD);
  Serial.setTimeout(5);
  while (!Serial) {
    // wait for serial port to connect.
  }
  delay(500);

  // enable the stepper motors
  digitalWrite(A0, HIGH);
  delay(1000);
  digitalWrite(A1, HIGH);

  Serial.println("Ready");
}

String command = "";
String buffer = "";
unsigned long timer = 0;
float timeTaken = 0;
//Vector<String> commands;

void loop() {
  if (Serial.available()) {
    command = Serial.readStringUntil('\n');
    command.trim();
    if (command[command.length()-1] != ' ') command += ' ';

    // check if first char is a viable move
    if (findName(command[0]) != -1) {
      timer = millis();
      moves = 0;
      extra_moves = 0;

      buffer = "";
      for (char c : command) {
        if (c != ' '){
          buffer += c;
        }
        else {
          executeMove(buffer);
          buffer = "";
          delay(turnDelay);  // 100, 50, 25
        }
      }

      timeTaken = ((float)(millis() - timer - turnDelay)) / 1000;
      Serial.print("Time taken: ");
      Serial.print(timeTaken, 3);
      Serial.print(" seconds. Moves: ");
      Serial.print(moves);
      Serial.print(" (");
      Serial.print(moves + extra_moves);
      Serial.print("). TPS: ");
      Serial.println((moves + extra_moves)/timeTaken, 2);

    } else {
      // change motor settings
      // format: "<stepDelay> <turnDelay>"

      int counter = 0;
      buffer = "";
      for (char c : command) {
        if (c != ' ') {
          buffer += c;
        }
        else {
          if (counter == 0) {
            stepDelay = buffer.toInt();
            buffer = "";
            counter++;
            Serial.print("stepDelay = ");
            Serial.print(stepDelay);
          } else {
            turnDelay = buffer.toInt();
            Serial.print("; turnDelay = ");
            Serial.print(turnDelay);
          }
        }
      }
      Serial.println();

    }

  }
}

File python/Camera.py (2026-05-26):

import cv2
import numpy as np
from time import sleep, time
from pygrabber.dshow_graph import FilterGraph

#                 0       1         2         3       4        5
COLOUR_NAMES = ("red", "orange", "yellow", "green", "blue", "white")
RGB_COLOUR_VALUES = ((255, 0, 0), (255, 128, 0), (255, 255, 0), (0, 255, 0), (0, 0, 255), (255, 255, 255))  # ideal values
COLOUR_HUE_RANGES = (0, 3, 23, 45, 84, 146, 181)  # (0, 3, 25, 53, 70, 160, 181)
WHITE_LIMITS = (60, 185, 120, 75, 130)  # low max s, [max s, min v, min h, max, h]
BAD_RED_LIMITS = (8, 130)  # max hue, max value
BAD_GREEN_LIMITS = (40, 175)  # min hue, max v - green for Value below threshold, yellow for above
BOX_COLOUR = (255, 0, 210)

# rubiks corner-piece colours in order of top, right, front
CORNER_COLOURS = ((5, 4, 0), (5, 0, 3), (5, 3, 1), (5, 1, 4), (2, 4, 1), (2, 1, 3), (2, 3, 0), (2, 0, 4))

# camera variables
CAMERA_RESOLUTION = (640, 480)
CAMERA_NAME = "Trust Webcam"
CAMERA_EXPOSURE = -1
DESIRED_CONTRAST = 2000

# find available camera devices
devices = FilterGraph().get_input_devices()
print("Available cameras:", *enumerate(devices))


def classify_hsv_colour(hsv_colour):
    h, s, v = hsv_colour

    # white - low Saturation and high Value
    if (s <= WHITE_LIMITS[0]) or (s <= WHITE_LIMITS[1] and v >= WHITE_LIMITS[2]
                                  and WHITE_LIMITS[3] <= h <= WHITE_LIMITS[4]):
        return 5

    # special case to determine red or orange for low hue
    if COLOUR_HUE_RANGES[1] <= h <= BAD_RED_LIMITS[0]:
        # red for Value below v, orange for above
        return 0 if v <= BAD_RED_LIMITS[1] else 1

    # special case to determine green or yellow
    if BAD_GREEN_LIMITS[0] <= h <= COLOUR_HUE_RANGES[3]:
        # green for Value below threshold, yellow for above
        return 3 if v <= BAD_GREEN_LIMITS[1] else 2

    # determine colour (match to colour hue ranges)
    for i in range(len(COLOUR_HUE_RANGES) - 1):
        if COLOUR_HUE_RANGES[i] <= h < COLOUR_HUE_RANGES[i + 1]:
            return i % 5  # wrap back around to red

    return None

def classify_hsv_colours(hsv_colours):
    return [classify_hsv_colour(col) for col in hsv_colours]

def get_hidden_corner_colour(colour1, colour2):
    # find matching piece with matching colours in same order
    correct_order = (colour1, colour2)
    for corner in CORNER_COLOURS:
        for i in range(3):
            # if the current corner and the next one (wrapped around)
            # equal the correct order -> return the corner after that
            if (corner[i], corner[(i + 1) % 3]) == correct_order:
                return corner[(i + 2) % 3]
    return None


class Camera:
    def __init__(self, device_id, flip_upsidedown=False, name=None, box_coords=None):
        self.device_id = device_id
        self.flip_upsidedown = flip_upsidedown
        self.name = name
        self.label = None  # label from GUI script
        self.hidden_corner_indexes = None
        self.hidden_corner_text_coords = None
        self.width, self.height = CAMERA_RESOLUTION
        self.box_coords = box_coords

        if not(len(devices) > device_id and devices[device_id] == CAMERA_NAME):
            self.cap = None
            return

        try:
            # Connect to camera:
            self.cap = cv2.VideoCapture(device_id, cv2.CAP_DSHOW)

            # Apply camera settings:
            # set camera resolution
            self.cap.set(cv2.CAP_PROP_FRAME_WIDTH, self.width)
            self.cap.set(cv2.CAP_PROP_FRAME_HEIGHT, self.height)
            # set exposure
            self.cap.set(cv2.CAP_PROP_EXPOSURE, CAMERA_EXPOSURE)
            self.cap.set(cv2.CAP_PROP_BUFFERSIZE, 0)

            print("Connected to camera", device_id)
        except Exception as e:
            self.cap = None
            print(e)


    def set_box_coords(self, path):
        with open(path, "r") as f:
            self.box_coords = [list(map(int, l.split())) for l in f.readlines()]
            f.close()

    def get_frame(self):
        if not self.cap: return None
        ret, frame = self.cap.read()

        if not ret or frame is None:
            return None

        # flip image 180 degrees
        if self.flip_upsidedown:
            cv2.rotate(frame, cv2.ROTATE_180, frame)

        # convert to RGB
        frame = cv2.cvtColor(frame, cv2.COLOR_BGR2RGB)

        # increase image contrast
        cv2.normalize(frame, frame, 0, DESIRED_CONTRAST, cv2.NORM_MINMAX)

        return frame

    def release(self):
        self.cap.release()

    def get_median_hsv_colours(self, img):
        # get the median HSV in each given pixel coord
        colours = []
        hsv_img = cv2.cvtColor(img, cv2.COLOR_RGB2HSV)

        for quad in self.box_coords:
            pts = np.array(quad)
            # get the bounding box of the quad
            x, y, w, h = cv2.boundingRect(pts)
            area = hsv_img[y:y + h, x:x + w]
            # area = cv2.GaussianBlur(area, (5, 5), 0)

            # shift points to new area space coords
            pts_shifted = pts - [x, y]

            # mask quad area
            mask = np.zeros((h, w), dtype=np.uint8)
            cv2.fillPoly(mask, [pts_shifted], 255)

            # get pixels with mask applied
            pixels = area[mask == 255]

            if len(pixels) == 0:
                print("Median calculation failed")
                colours.append(None)
            else:
                # append median hsv values
                colours.append(np.median(pixels, axis=0).astype(int))

        return colours

    def draw_boxes(self, img):
        # draw squares around the given pixel coords
        for box_ind, box in enumerate(self.box_coords):
            # img = cv2.rectangle(img, (x - size, y - size), (x + size, y + size), BOX_COLOUR, 2)
            pts = np.array(box, np.int32)
            pts = pts.reshape((-1, 1, 2))
            img  = cv2.polylines(img, [pts], True, BOX_COLOUR, 2)
        return img

    def write_colour_values(self, img, colour_values, colours):
        # write given colour values next to every coord
        for i, quad in enumerate(self.box_coords):
            curr_colour = BOX_COLOUR if colours[i] is None else RGB_COLOUR_VALUES[colours[i]]

            centre_x = sum([a for a, b in quad])//4
            centre_y = sum([b for a, b in quad])//4
            img = cv2.putText(img, f"{colour_values[i]}",
                              (centre_x - len(str(colour_values[i])) // 2 * 10, centre_y - 15),
                              cv2.FONT_HERSHEY_SIMPLEX, 0.5, curr_colour, 2, 2)
        return img

    def get_hidden_corner_colours(self, colours):
        result = []
        for i1, i2 in self.hidden_corner_indexes:
            result.append(get_hidden_corner_colour(colours[i1], colours[i2]))
        return result



if __name__ == "__main__":
    print("Nope")
